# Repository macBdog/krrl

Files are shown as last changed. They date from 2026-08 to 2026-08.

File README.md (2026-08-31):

# KRRL-01

Control software and operator UI for the KRRL-01 vinyl record lathe.

**Hardware:** Raspberry Pi 4 (brain + audio + camera) and Arduino Mega 2560 (real-time motors and IO).  
**OS:** Raspberry Pi OS Lite 64-bit (Debian). See [docs/OS.md](docs/OS.md).

The Pi never generates step pulses. The Mega owns platter, X (lead screw), Z (depth), heated stylus PID, chip vacuum, limits, and E-stop.

## Quick start (desktop, no hardware)

```bash
cd krrl-01
PYTHONPATH=host python3 -m krrl --dry-run --port 8080
```

Open http://127.0.0.1:8080 — Live, Experiment, Cut, and Setup all run against a Mega simulator.

```bash
PYTHONPATH=host python3 -m krrl.check
```

## Pi (with Mega)

1. Flash **Raspberry Pi OS Lite 64-bit**.
2. Run `sudo bash deploy/tune-pi.sh`.
3. Copy this tree to `/opt/krrl-01`.
4. `sudo cp deploy/krrl.service /etc/systemd/system && sudo systemctl enable --now krrl`
5. Connect the Mega on USB (`/dev/ttyACM0`). I2S DAC HAT for the cutter amp; not the 3.5 mm jack.

## Layout

| Path | Role |
|---|---|
| `firmware/krrl_mega/` | Mega 2560 sketch (lathe) |
| `firmware/krrl_player/` | Nano sketch (player turntable variant) |
| `host/krrl/` | Python host |
| `ui/` | Operator console |
| `config/machine.yaml` | Calibration and devices |
| `docs/PROTOCOL.md` | Serial line protocol |
| `docs/PLAYER.md` | Player turntable variant |
| `docs/TACHOMETER.md` | Optional optical index monitor + marking/machining |
| `docs/CALIBRATION.md` | Open-loop platter speed calibration |
| `hardware/` | Drive/bearing/belt/stepper/phono notes + BOM |
| `deploy/` | systemd, PipeWire, OS tune |

## Player variant

A lower-cost, playback-only turntable on an **Arduino Nano only** (no Pi, no UI):
33/45/78 with ±8% pitch and start/stop, reusing the lathe belt drive, TMC2209
driver and motion core. See [docs/PLAYER.md](docs/PLAYER.md).

## Cut v1

Constant pitch only. Groove feed is `mm/s = rpm/60 * (25.4 / lpi)`. Variable-pitch preview is reserved for v2.

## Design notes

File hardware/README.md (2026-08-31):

# KRRL-01 hardware notes

Engineering notes and bill of materials for the mechanical drive and the player's
phono electronics. These are design notes, not a build manual — dimensions are
targets to design around, and part numbers are representative families, not
mandated SKUs.

## Shared drive architecture

The lathe and the standalone player share one drive: a **raised platter on a
central spindle, belt-driven around the spindle**, with the belt **tensioner
around that central shaft**. Raising the platter leaves the space underneath for
the lathe's **X-axis lead screw and carriage**, which passes below the platter.
The player uses the identical drive minus the X/Z/cutter hardware.

```
                 14" (356 mm) platter
   ┌──────────────────────────────────────────────┐
   └───────────────────────┬────────────────────────┘
              sub-platter / belt pulley (on spindle)
        ╔═══════════════════╪═══════════════════╗
        ║  bearing cartridge (moment-stiff)     ║  <- rigidity lives here
        ╚═══════════════════╪═══════════════════╝
                          spindle
   ── belt ── ( motor pulley )      ( idler tensioner )
   ─────────────── X-axis lead screw runs UNDER platter ───────────────
                          plinth / chassis
```

Design consequences that thread through the rest of these notes:

- **Rigidity is a moment problem.** The cutting stylus and the record rim sit at
  ~178 mm radius, so what matters is the platter's resistance to *tilting*, set
  almost entirely by the spindle bearing arrangement (see `drive.md`).
- **The belt sets the layout, not a big reduction.** The step ISR runs at
  `ISR_HZ = 20 kHz` and a step needs two ticks, so the platter step rate must
  stay below ~10 kHz (keep < 8 kHz for margin). At the base `steps_per_rev` of
  3200 and 78 rpm that is 4160 steps/s, so the belt ratio must stay near **1:1
  (≤ ~2:1)**. The belt is there for the raised-platter geometry and vibration
  isolation, not gearing.
- **Speed is open-loop.** There is no runtime speed feedback; absolute accuracy
  comes from calibrating `steps_per_rev` (see
  [`docs/CALIBRATION.md`](../docs/CALIBRATION.md)). The player has no speed
  sensor; the lathe may optionally fit a once-per-rev optical index as a passive
  at-speed monitor ([`docs/TACHOMETER.md`](../docs/TACHOMETER.md)).

## Contents

| File | Covers |
|---|---|
| [`drive.md`](drive.md) | Platter bearings, belt spec, stepper + driver, belt tensioner |
| [`phono.md`](phono.md) | Minimal-component phono amplification + RIAA EQ (player) |
| [`BOM.csv`](BOM.csv) | Consolidated bill of materials (lathe / player / both) |
| [`player_pcb/`](player_pcb) | Player single-board KiCad design (Nano + TMC2209 + RIAA + I/O), fab outputs |

## Related

- Firmware: [`firmware/krrl_mega/`](../firmware/krrl_mega) (lathe),
  [`firmware/krrl_player/`](../firmware/krrl_player) (player).
- Speed calibration: [`docs/CALIBRATION.md`](../docs/CALIBRATION.md).
- Optical index marking/machining: [`docs/TACHOMETER.md`](../docs/TACHOMETER.md).

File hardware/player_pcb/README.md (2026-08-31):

# Player mainboard (KiCad)

A single fabricable 2-layer PCB that carries the whole player turntable
electronics: the **Arduino Nano**, a **TMC2209** stepper-driver module, the
**RIAA phono preamp**, and all **front-panel I/O**. Speed is open-loop
feedforward (see [`docs/CALIBRATION.md`](../../docs/CALIBRATION.md)); the board
has no speed sensor.

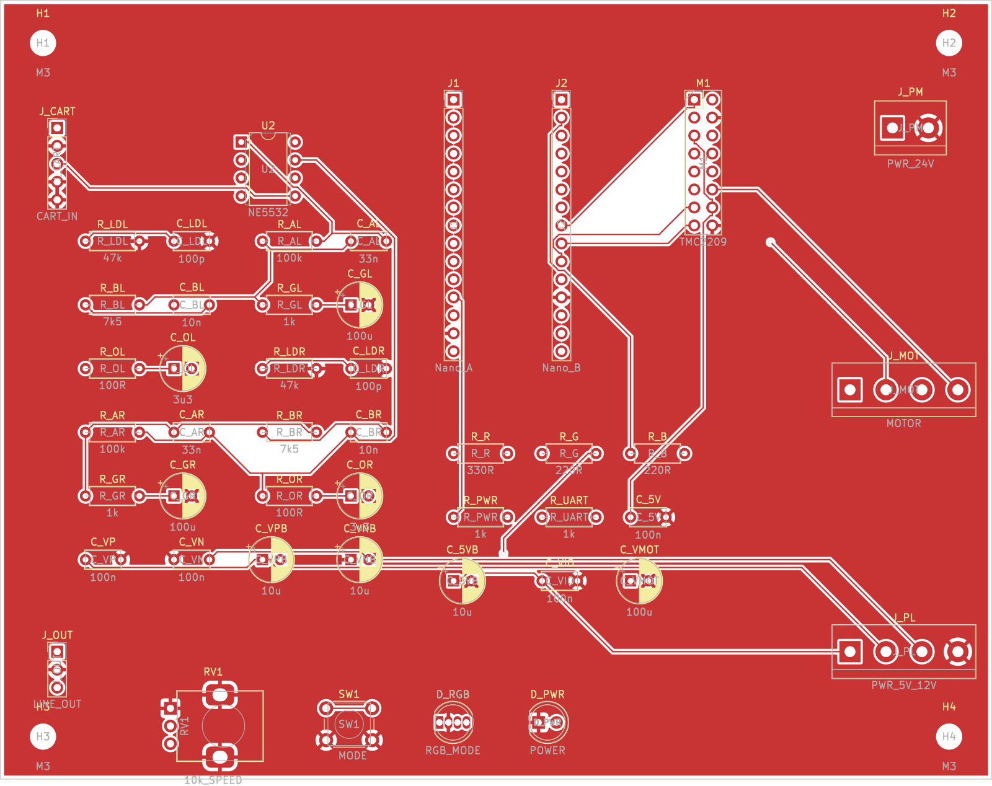
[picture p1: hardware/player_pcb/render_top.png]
Player mainboard — top


Open in KiCad 7+: `krrl_player.kicad_pro` (board `krrl_player.kicad_pcb`). It is a
**standalone board** (no schematic sheet) — every connection is defined by the
board nets, tabulated below and in [`NETLIST.txt`](NETLIST.txt).

## Board sections

- **Left:** analog phono — cartridge input `J_CART`, `NE5532` (`U2`), the RIAA
  network, and line output `J_OUT`.
- **Centre/right:** digital — the Nano (`J1`/`J2`) and the TMC2209 module (`M1`).
- **Right edge:** power/motor terminals (`J_PM`, `J_PL`, `J_MOT`).
- **Front edge:** controls — mode button `SW1`, speed pot `RV1`, RGB mode LED
  `D_RGB`, power LED `D_PWR`.

The analog section sits at the opposite end from the motor terminal and TMC to
keep the 5 mV cartridge signal away from stepper switching (see
[`hardware/phono.md`](../phono.md) for the EMI/grounding rationale).

## Power supply (external, separate — specify when ordering the PSU)

The board has **no on-board regulators**; it expects an external multi-rail
supply. A linear analog rail keeps the phono stage quiet.

| Rail | Use | Min current | Enters at |
|---|-----|---|---|
| +24 V | Stepper (TMC `VMOT`) | ~1.5 A | `J_PM` pin 1 |
| +5 V | Logic (Nano, TMC `VIO`, LEDs) | ~0.5 A | `J_PL` pin 1 |
| +12 V | Phono op-amp V+ | ~50 mA | `J_PL` pin 2 |
| −12 V | Phono op-amp V− | ~50 mA | `J_PL` pin 3 |
| GND | Common return | — | `J_PM` pin 2, `J_PL` pin 4 |

All grounds meet at the board (single GND pour = star point). Keep the PSU's
motor return and analog return joined only at the supply to avoid a ground loop.
±12 V may be ±15 V if preferred (NE5532 max ±22 V).

## Connectors

**`J_PM` — 24 V motor power** (2-pos): 1 = +24 V, 2 = GND.
**`J_PL` — logic/analog power** (4-pos): 1 = +5 V, 2 = +12 V, 3 = −12 V, 4 = GND.
**`J_MOT` — stepper motor** (4-pos): 1 = 2B, 2 = 2A, 3 = 1A, 4 = 1B (coil pairs
1A/1B and 2A/2B).
**`J_CART` — cartridge in** (1×5): 1 = L-hot, 2 = L-gnd, 3 = R-hot, 4 = R-gnd,
5 = shield (2/4/5 → GND).
**`J_OUT` — line out** (1×3): 1 = L, 2 = GND, 3 = R (fit an RCA pigtail).

## Front panel

| Control | Part | Wiring |
|---|---|---|
| Mode button | `SW1` momentary | to `MODE` (Nano D6, `INPUT_PULLUP`) and GND |
| Speed pot | `RV1` 10k lin | 1 → GND, 2 (wiper) → A0, 3 → +5 V |
| Mode LED | `D_RGB` common-cathode | R/G/B anodes via `R_R`/`R_G`/`R_B` → D9/D10/D11; cathode → GND |
| Power LED | `D_PWR` | +5 V → `R_PWR` → anode; cathode → GND |

RGB colours (firmware): off = stopped, green = 33, blue = 45, red = 78; blinks
while spinning up, solid at speed.

## Nano pin usage (`J1` side A, `J2` side B)

| Net | Nano pin | Header |
|-----|---|---|
| +5 V | 5V | J1.12 |
| GND | GND | J1.14, J2.12 |
| Speed pot wiper | A0 | J1.4 |
| STEP | D3 | J2.10 |
| DIR | D4 | J2.9 |
| EN | D5 | J2.8 |
| MODE | D6 | J2.7 |
| LED R / G / B | D9 / D10 / D11 | J2.4 / J2.3 / J2.2 |
| TMC UART (opt.) | D1 TX / D0 RX | J2.15 / J2.14 |

## TMC2209 module header (`M1`, 2×8)

Follows the StepStick / A4988-compatible layout so a SilentStepStick-class
TMC2209 mounts here. **Verify your module's pinout — especially the PDN/UART
pin — before soldering.**

| Pin | Net | Pin | Net |
|----:|-----|----:|-----|
| 1 | EN | 2 | +24 V (VMOT) |
| 3 | MS1 → +5 V | 4 | GND |
| 5 | MS2 → +5 V | 6 | 2B |
| 7 | PDN/UART | 8 | 2A |
| 9 | (nc) | 10 | 1A |
| 11 | (nc) | 12 | 1B |
| 13 | STEP | 14 | +5 V (VIO) |
| 15 | DIR | 16 | GND |

`MS1`/`MS2` are tied to +5 V for **1/16 microstepping** in standalone STEP/DIR
mode (matches the firmware `steps_per_rev = 3200`). For the optional UART build
(`-DTMC_UART`), the Nano UART reaches `PDN` via `R_UART` (1 k); set the module
address as needed.

## RIAA phono

One `NE5532` (`U2`) as two non-inverting active-feedback RIAA stages. Per-channel
values and the design rationale are in [`hardware/phono.md`](../phono.md):
47 k∥100 pF load, `R_A` 100 k / `C_A` 33 n / `R_B` 7.5 k / `C_B` 10 n feedback,
`R_G` 1 k + `C_G` 100 µF gain-set, `R_O` 100 Ω + `C_O` 3.3 µF output. Treat the
values as a verified-by-calculator starting point.

## Board specs / fabrication

- **2-layer** FR4, 1.6 mm, 1 oz copper; **140 × 110 mm**.
- Design rules: 0.2 mm track / 0.2 mm clearance; vias 0.8 mm / 0.4 mm; GND pours
  on both layers.
- Fab outputs: [`gerbers/`](gerbers) (RS-274X + Excellon `.drl`) and
  [`krrl_player_gerbers.zip`](krrl_player_gerbers.zip). BOM in
  [`BOM.csv`](BOM.csv).

### Regenerate

The board is generated from source (KiCad 7 `pcbnew` + freerouting):

```
FREEROUTING_JAR=/path/to/freerouting-1.9.0.jar ./route.sh   # place + net + autoroute
./fab.sh                                                    # gerbers + drill + renders
```

`build_pcb.py` is the source of truth for components and connections; edit it and
re-run to change the design.

## Status / caveats

- **Fully routed, 0 unrouted connections** at the rules above; placement and
  routing are auto-generated (freerouting) — review in KiCad before ordering.
- Verify the **TMC2209 module** and **RGB LED** pinouts against your exact parts.
- RIAA values and the external PSU rails should be confirmed for your build.
- This is a design deliverable validated by connectivity + Gerber export; it has
  **not been fabricated or bench-tested**.

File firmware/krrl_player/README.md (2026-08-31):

# Nano player firmware

Minimal belt-drive **playback** turntable: 33/45/78 with a ±8% pitch trim and a
single mode button, and nothing else. No host, no serial protocol, no cutter,
heater or vacuum. It reuses the KRRL-01 belt drive motor, TMC2209 driver and the
lathe's open-loop step-rate motion core (`playspeed.h`, `platter.cpp` derived
from `firmware/krrl_mega/motion.cpp`).

The front panel is a single **momentary mode button**, a **speed pot**, a
**multicolour (RGB) mode LED** and a **power LED** — matching the single-board
design in [`hardware/player_pcb/`](../../hardware/player_pcb).

Open `krrl_player.ino` in Arduino IDE (board: **Arduino Nano**, ATmega328P).
The default build is STEP/DIR only and needs no libraries.

## Wiring (Arduino Nano)

| Signal | Pin | Notes |
|---|-----|---|
| Platter STEP | D3 | to TMC2209 STEP |
| Platter DIR | D4 | to TMC2209 DIR |
| Platter EN | D5 | active LOW |
| MODE button | D6 | momentary to GND; cycles STOP → 33 → 45 → 78 |
| Mode LED R / G / B | D9 / D10 / D11 | common-cathode RGB, each anode via a series R |
| Speed pot | A0 | 10k linear pot wiper; ends to 5V and GND |
| TMC UART | D0/D1 | optional, `-DTMC_UART` (RX/TX to PDN_UART via 1k) |

The mode button is `INPUT_PULLUP`, wired button-to-ground. The speed pot is a
10k linear potentiometer: outer legs to 5V and GND, wiper to A0. Pins are in
`config.h`. The **power LED is hardwired to +5V** on the board (not a Nano pin).

**Mode button** cycles `STOP → 33 → 45 → 78 → STOP`; STOP spins the platter
down. The **RGB LED** shows the mode — off = stopped, green = 33, blue = 45,
red = 78 — blinking while spinning up and solid once at speed.

The **speed pot** is a continuous pitch trim: **centre detent reads 0%** (a small
deadband holds nominal speed), each end reaches **±8%**, smoothed so the platter
speed doesn't jitter.

## Speed: open-loop feedforward

Platter speed is open-loop — the step rate sets the speed, with no runtime
control loop and no on-board speed sensor. Set absolute speed by **calibration**
([`docs/CALIBRATION.md`](../../docs/CALIBRATION.md)); the fine trim is
`KRRL_SPEED_TRIM_PPM` in `playspeed.h` (or adjust `KRRL_PLATTER_STEPS_PER_REV`).
Speed verification is done with external calibration equipment, not by the
firmware. The `LED` at-speed indication reflects the feedforward ramp reaching
the commanded rate.

## TMC2209 current / microsteps (optional)

Default is STEP/DIR only; the driver runs at its jumper defaults. To set current
and microsteps over UART at boot:

1. Install [TMCStepper](https://github.com/teemuatlut/TMCStepper).
2. Build with `-DTMC_UART`.
3. Wire PDN/UART to the Nano hardware UART (D0/D1); driver address `00`
   (MS1/MS2 low), same as the lathe platter.

## Speed math

`playspeed.h` is shared, pure C, and unit-tested on the host:

```
cd firmware/krrl_player/test
c++ -std=c++11 -o test_playspeed test_playspeed.cpp && ./test_playspeed
```

Step rate is `sps = rpm / 60 * 3200`, matching the lathe platter
(`PLATTER_STEPS_PER_REV`). Pitch is multiplicative: `rpm * (1 ± pct/100)`.

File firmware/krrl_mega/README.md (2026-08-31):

# Mega 2560 firmware

Open `krrl_mega.ino` in Arduino IDE (board: **Arduino Mega or Mega 2560**).

Default build is STEP/DIR only and does not need libraries.

To configure TMC2209 current/microsteps over UART at boot:

1. Install [TMCStepper](https://github.com/teemuatlut/TMCStepper)
2. Add compile flag `-DTMC_UART` (Arduino CLI) or `#define TMC_UART` in `config.h`
3. Wire PDN/UART to Serial1 (pins 18/19) with the usual 1 kΩ TX/RX arrangement
4. Set MS1/MS2 addresses: platter 00, X 01, Z 10

Pins match `config.h` and the comments in `config/machine.yaml`.

## Platter speed: open-loop feedforward

The platter runs open-loop — the step rate sets the speed, with no runtime
control loop. Set absolute speed by **calibration**
([`docs/CALIBRATION.md`](../../docs/CALIBRATION.md)); the fine trim is
`PLATTER_CAL_PPM` in `config.h` (or adjust `PLATTER_STEPS_PER_REV`).

The 1-pulse-per-rev optical tach (`PIN_TACH`, pin 3) is a **passive monitor**:
it feeds telemetry `rpm` and the `START` at-speed interlock but does not steer
the step rate. See [`docs/TACHOMETER.md`](../../docs/TACHOMETER.md) for the
sensor and the platter marking/machining (shared with the player variant).

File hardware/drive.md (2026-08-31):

# Drive: bearings, belt, stepper, tensioner

Shared by the lathe and the player. See [`README.md`](README.md) for the
raised-platter, belt-around-the-spindle architecture and the constraints it
imposes.

## 1. Platter spindle bearings (rigidity at the 14" rim)

The platter is 356 mm (14") diameter, so the load that matters is the **tilting
moment** at the ~178 mm rim — from the cutting stylus on the lathe and from any
off-centre load on either machine. A bearing that is stiff radially but weak in
*moment* lets the rim nod by microns, which reads as runout, wow and (on the
lathe) a wandering cut. Maximise **moment (tilt) stiffness**, then radial, then
axial; keep friction and noise low for the audio path.

Target: platter face and rim runout **< 5 µm TIR**; no perceptible rock at the
rim by hand.

### Recommended: preloaded angular-contact pair, back-to-back (baseline)

Two precision angular-contact ball bearings (7205/7206-class, **bore 25–30 mm**,
**P5/ABEC-5 or better**) mounted **back-to-back (DB / "O")** in a rigid cartridge.
Back-to-back places the contact lines' apexes *outboard*, which widens the
effective support span and is what buys the tilt stiffness at the rim. Set a
**light-to-medium axial preload** (ground spacer or a preload nut + Belleville
washer) to remove all play — preload is what makes it feel solid.

- Spindle: hardened, ground steel, **Ø25–30 mm**, seats to h6; housing bores H7.
- Space the two bearings as far apart on the spindle as the raised height allows;
  span dominates tilt stiffness.
- Angular-contact (point/line contact, low drag) runs quieter than tapered
  roller — preferred for the player.

### Alternative: thin-section crossed-roller bearing (most compact/stiff)

A single **crossed-roller** (e.g. THK RA/RB, IKO CRB, Kaydon) or four-point-contact
thin-section bearing takes radial, axial **and moment** load in one race. Highest
tilt stiffness per height and ideal for a raised platter with a large central
boss, at higher cost and more sensitivity to housing flatness. Size the bore to
the sub-platter boss (typically Ø50–90 mm).

### Alternative: preloaded tapered-roller pair (max stiffness, more rumble)

Back-to-back tapered rollers (machine-tool spindle style) give the highest
stiffness and load capacity — attractive for heavy cutting — but have more drag
and running noise, so they are a poorer fit for the player. Use only if lathe
cutting loads demand it.

### Avoid

A single deep-groove ball bearing + a flat thrust washer is cheap but has almost
no moment stiffness — the 14" rim will nod. Not acceptable for this goal.

## 2. Drive belt

The belt exists for **layout and vibration isolation**, not reduction (ratio must
stay near 1:1 — see the step-rate ceiling in `README.md`).

- **Type:** endless **flat ground belt** (polyurethane/neoprene, ~**6 mm wide ×
  0.5–0.65 mm**) or a **round belt Ø3–4 mm**. Both mechanically low-pass motor
  vibration, keeping rumble/flutter down — the classic turntable choice.
  A **GT2/6 mm timing belt** is the positive-drive alternative (exact ratio, no
  creep) but couples motor cogging into the platter; only choose it if belt creep
  under lathe cutting load is a problem, and rely on TMC stealthChop to keep the
  motor smooth.
- **Pulleys:** **crowned** (slightly barrelled) so a flat/round belt self-tracks
  — no flanges, cleaner look. The sub-platter/spindle is the driven pulley; the
  motor pulley diameter is chosen to keep ratio ≈ 1:1.
- **Wrap:** aim for **≥ 180°** contact on the drive pulley; the idler tensioner
  (below) is what increases wrap and holds it constant.
- **Tension:** low and constant — of order **2–5 N** for a round/flat isolation
  belt. Enough to avoid slip under acceleration/cut load, no more (over-tension
  loads the spindle bearing and adds rumble).

## 3. Stepper and driver

- **Motor:** **NEMA 17, high-torque** as the shared baseline — 42 mm frame,
  **≥ 0.5 N·m holding**, ~**1.5 A/phase**, 200 full-steps/rev (1.8°), e.g. a
  48 mm-stack `17HS19-2004S1`-class. Ample for the player and light cuts; the
  platter's large inertia is handled by the firmware's rate slew, and open-loop
  torque margin resists cut load without losing steps.
- **Heavy cutting option:** **NEMA 23** (57 mm, 1.2–1.9 N·m) if lathe cutting
  loads are high. Note a torquey NEMA 23 can exceed the TMC2209's practical
  ~1.7 A RMS — pair it with a **TMC5160** or an external step/dir driver
  (DM542-class) instead.
- **Driver:** **TMC2209** (already in firmware — STEP/DIR at runtime, UART config
  at boot; `firmware/*/tmc.cpp`). Run **stealthChop** for a silent platter on the
  player; **spreadCycle** is available when the lathe needs peak torque. Set RMS
  current to the motor (firmware default 800 mA for the platter). **16
  microsteps** balances smoothness against the step-rate ceiling.
- **Supply:** **24 V** to the driver (better torque headroom, still within the
  TMC2209's ~28 V limit); logic at 5 V. Keep the motor supply electrically clean
  and separated from the phono stage (see `phono.md`).

## 4. Belt tensioner (aesthetic, constant-tension)

A **constant-tension** device beats a fixed one: it takes up belt stretch and
thermal drift and keeps flutter low. Two clean options, both hiding the mechanism
under the raised platter:

### Preferred: pivoting idler arm with concealed preload

A short **polished/anodised aluminium arm** pivots on a bearing post and carries a
small **ball-bearing crowned idler pulley** that rides the slack side of the belt.
Preload the arm with either:

- a **concealed extension spring** tucked inside the arm or behind the pillar, or
- a **magnetic** preload — a pair of small neodymium magnets (one on the arm, one
  on the chassis) tuned to the target belt force — giving a spring-free, wear-free,
  visually clean pull.

The arm both **tensions** and **increases wrap** on the drive pulley. Set the
preload to land the 2–5 N belt tension; a soft rate keeps tension near-constant
over the arm's travel.

### Minimalist: eccentric motor pod

Mount the motor on a **round pod with an eccentric bore** (or on a slotted plate);
rotate/slide to tension, then lock with a single hidden screw. No visible
spring — the tension "mechanism" reads as a clean turned boss. Fixed rather than
constant-tension, so revisit after break-in.

Either way use a **bearing idler** (not a bushing) so it adds no drag or noise,
and crown it so the belt self-centres.

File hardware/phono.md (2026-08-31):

# Phono amplification and RIAA EQ (player)

The standalone player needs to turn a cartridge's tiny signal into a line-level
output with the **RIAA** replay curve applied. This note targets a **moving-magnet
(MM)** cartridge and the **fewest components** that do it well.

> The hard part here is not the circuit — it is **noise**. An MM output is only
> ~5 mV, sitting centimetres from a stepper and its driver. Read the EMI section
> before the topology; it decides whether this works.

## Cartridge and loading

- **Cartridge:** moving-magnet (MM). Output ~**3–5 mV @ 1 kHz, 5 cm/s**.
- **Load:** **47 kΩ** to ground in parallel with **~100–220 pF** (include tonearm
  cable capacitance in the total; many MM carts want ~200–300 pF total). Put the
  47 kΩ and a small load cap right at the preamp input.

## Target response

Apply the inverse-RIAA replay curve, i.e. three time constants:

| Constant | Freq | Role |
|---|---|---|
| 3180 µs | 50.0 Hz | bass turnover (boost below) |
| 318 µs | 500 Hz | mid |
| 75 µs | 2122 Hz | treble roll-off |

Aim for the curve within **±0.5 dB** (1% metal-film resistors, 1–2.5% film caps).
Midband gain ~**40 dB (×100) @ 1 kHz** brings 5 mV up to ~0.5 V line level.

## Minimal topology: one dual op-amp, active-feedback RIAA

Fewest parts: a single **dual op-amp** does both channels, each in a
**non-inverting, active-feedback RIAA** stage. Per channel that is one gain
device plus a handful of passives — no separate buffers or multi-stage EQ.

- **Op-amp:** low-noise, unity-gain-stable **NE5532** (cheap, quiet), or
  **OPA2134 / LM4562** for lower noise/distortion. One dual package = stereo.
- **Per channel (see values below):** 47 kΩ load + load cap; gain resistor `Rg`
  (with a large DC-blocking cap to ground); feedback network `R_A, C_A` and
  `R_B, C_B` that set the three time constants; input DC-block + a small RF cap.

```
  cart o──┬──[47k]──┬── + in >\
          │        (Cload)     \____ out ──[Rout]──|| Cout ── line out
        (Cin DC)               /
                   ┌── − in ─/
                   │
          Rg ─ Cg(DC) ─ gnd        feedback: out ─ R_A ─┬─ − in
                                                        └─(R_B + C_B)┘,  C_A across R_A
```

### Starting values (verify with a RIAA calculator, then trim)

These land the three breakpoints close; C_A/R_B interact, so verify and trim on
the bench or in a calculator before committing:

- `Cload` ≈ 100 pF (bring total incl. cable to what the cartridge specifies)
- `Rg` ≈ 1 kΩ, `Cg` ≈ 100 µF (sets midband gain, blocks DC)
- `R_A` ≈ 100 kΩ, `C_A` ≈ 33 nF  (anchors the 3180 µs turnover)
- `R_B` ≈ 7.5 kΩ, `C_B` ≈ 10 nF  (`R_B·C_B` = 75 µs, the treble roll-off — exact)
- `Cin` ≈ 1–3.3 µF film (input DC block), plus ~100–470 pF at the input node for RF
- `Rout` ≈ 100 Ω, `Cout` ≈ 2.2–10 µF (output DC block)

### Easier-to-tune alternative

If you have a bench and want the curve nailed without interaction: a **flat
low-noise gain stage → passive RIAA network → buffer**. More parts, but each time
constant is an independent RC, so it is simpler to trim. Choose this only if the
single-stage feedback curve is fighting you.

A **dedicated phono IC** is the even-fewer-parts route if you prefer an
integrated part over the op-amp + passives, at the cost of flexibility.

## Power

- **± 12–15 V dual rail** from a small **linear** regulated supply is simplest and
  quietest. If running single-supply (e.g. 24 V), bias the op-amp to a
  **virtual ground** (rail/2) and AC-couple in and out.
- **Do not share the motor's 24 V rail.** Give the phono stage its own regulated,
  filtered supply; the stepper's switching current on a shared rail will inject
  hum/buzz straight into a 5 mV signal.
- Decouple each op-amp rail with 100 nF + 10 µF at the package.

## EMI, grounding and layout (the part that actually matters)

- **Separate the phono board from the motor and driver** physically and put it in
  a **shielded (steel/mu-metal) enclosure**. Keep step/dir and motor-phase wires
  well away from the cartridge leads; twist the motor pairs.
- **Shielded cartridge leads**, as short as practical; connect the shield at one
  end only (preamp end) to avoid a ground loop.
- **Star ground:** one reference point; separate the motor-supply return from the
  audio ground and join only at the star. No ground loops between the platter
  frame, motor supply, and audio.
- Run the platter motor in **stealthChop** (TMC2209) for the quietest electrical
  and acoustic signature during playback.
- Add the small input RF cap and keep the input node tiny; the 47 kΩ node is a
  perfect antenna otherwise.

## Output

Line level ~**0.3–1 V RMS** at an output impedance of ~100 Ω, AC-coupled. Feed a
line input / integrated amp, not a second phono input.

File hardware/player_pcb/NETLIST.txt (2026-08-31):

KRRL-01 Player board — netlist (net: pads)

+12V: C_VP.1, C_VPB.1, J_PL.2, U2.8
+24V: C_VMOT.1, J_PM.1, M1.2
+5V: C_5V.1, C_5VB.1, C_VIO.1, J1.12, J_PL.1, M1.14, M1.3, M1.5, RV1.3, R_PWR.1
-12V: C_VN.2, C_VNB.2, J_PL.3, U2.4
BML: C_BL.2, R_BL.1
BMR: C_BR.2, R_BR.1
DIR: J2.9, M1.15
EN: J2.8, M1.1
FBL: C_AL.1, R_AL.1, R_BL.2, R_GL.1, U2.2
FBR: C_AR.1, R_AR.1, R_BR.2, R_GR.1, U2.6
GML: C_GL.1, R_GL.2
GMR: C_GR.1, R_GR.2
GND: C_5V.2, C_5VB.2, C_GL.2, C_GR.2, C_LDL.2, C_LDR.2, C_VIO.2, C_VMOT.2, C_VN.1, C_VNB.1, C_VP.2, C_VPB.2, D_PWR.1, D_RGB.2, J1.14, J2.12, J_CART.2, J_CART.4, J_CART.5, J_OUT.2, J_PL.4, J_PM.2, M1.16, M1.4, RV1.1, RV1.MP, R_LDL.2, R_LDR.2, SW1.2
INL: C_LDL.1, J_CART.1, R_LDL.1, U2.3
INR: C_LDR.1, J_CART.3, R_LDR.1, U2.5
LEDB: J2.2, R_B.1
LEDG: J2.3, R_G.1
LEDR: J2.4, R_R.1
LOUTL: C_OL.2, J_OUT.1
LOUTR: C_OR.2, J_OUT.3
M1A: J_MOT.3, M1.10
M1B: J_MOT.4, M1.12
M2A: J_MOT.2, M1.8
M2B: J_MOT.1, M1.6
MODE: J2.7, SW1.1
OLL: C_OL.1, R_OL.2
OLR: C_OR.1, R_OR.2
OUTL: C_AL.2, C_BL.1, R_AL.2, R_OL.1, U2.1
OUTR: C_AR.2, C_BR.1, R_AR.2, R_OR.1, U2.7
PDN: J2.14, M1.7, R_UART.2
POTW: J1.4, RV1.2
PWRA: D_PWR.2, R_PWR.2
RGB_B: D_RGB.4, R_B.2
RGB_G: D_RGB.3, R_G.2
RGB_R: D_RGB.1, R_R.2
STEP: J2.10, M1.13
TX: J2.15, R_UART.1

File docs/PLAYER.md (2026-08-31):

# KRRL-01 Player (Nano variant)

A separate, lower-cost **playback** turntable. Where the lathe pairs a
Raspberry Pi with an Arduino Mega, the player is an **Arduino Nano only** — pure
hardware, no host, no UI, no serial protocol.

## What it does

- Playback at **33⅓ / 45 / 78** rpm, selected by a single **mode button**
  (cycles STOP → 33 → 45 → 78) with a **multicolour LED** showing the mode.
- Continuous **speed pot** (pitch trim) of **±8%** (centre detent = 0%).
- Smooth rate-slewed belt spin-up/down.
- **Open-loop feedforward speed** — no runtime control loop and **no speed
  sensor**. Set absolute speed via [docs/CALIBRATION.md](CALIBRATION.md). The
  LED reflects the feedforward ramp reaching the commanded rate.

No cutter, heater, vacuum, camera, audio pipeline, homing or limits — none of the
lathe's cut path is present.

## What it shares with the lathe

- The **belt drive stepper motor** and pulley/belt ratio.
- The **TMC2209** driver (STEP/DIR at runtime, optional UART config at boot).
- The **motion core**: the same Timer1 phase-accumulator step generation and the
  same open-loop speed math (`sps = rpm / 60 * 3200`). The platter steps-per-rev
  matches the lathe (`firmware/krrl_mega/config.h`, `config/machine.yaml`) and
  the shared math lives in `firmware/krrl_player/playspeed.h`.
- The **open-loop platter drive** and the calibration approach. See
  [docs/CALIBRATION.md](CALIBRATION.md). (The optional optical index monitor is a
  lathe-only feature — [docs/TACHOMETER.md](TACHOMETER.md).)

## Controls

A single momentary **mode button**, a **speed pot**, a **multicolour (RGB) mode
LED** and a **power LED**. Wiring and pins are in
[`firmware/krrl_player/README.md`](../firmware/krrl_player/README.md); the
single-board design is in [`hardware/player_pcb/`](../hardware/player_pcb).

| Control | Action |
|---|---|
| Mode button | Cycle STOP → 33 → 45 → 78 (STOP spins down) |
| Speed pot | Continuous ±8% pitch trim of the running speed; centre = 0% |
| RGB mode LED | off = stopped, green = 33, blue = 45, red = 78; blinks while spinning up |
| Power LED | Hardwired to +5V; power present |

## Firmware

`firmware/krrl_player/` — build for **Arduino Nano** (ATmega328P). Default build
is STEP/DIR only and needs no libraries. See the firmware README for the TMC2209
UART option and the host-side test of the speed math.

## Board

A single fabricable KiCad PCB (Nano + TMC2209 + RIAA phono + I/O) is in
[`hardware/player_pcb/`](../hardware/player_pcb), which also specifies the
required external power supply.

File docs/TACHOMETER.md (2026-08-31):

# Optical index mark (passive at-speed monitor)

Both KRRL-01 machines — the lathe (Mega) and the player (Nano) — drive the same
belt-driven platter with a stepper, **open-loop**. A stepper is nearly
synchronous, so the commanded step rate *is* the speed; torque margin keeps it
there. There is **no runtime speed control loop** — absolute accuracy comes from
[calibration](CALIBRATION.md), not feedback.

On the **lathe**, an optional **once-per-revolution optical index mark** is still
useful as a **passive at-speed / lost-step monitor**: it reports the platter's
actual speed for telemetry and the `START` interlock, but it never steers the
step rate. (A single mark per rev is far too slow to close a speed loop, and it
only sees average speed, not wow/flutter — which is why the drive is open-loop.)

The **player** carries **no speed sensor**: it is fully open-loop and its
at-speed LED simply reflects the feedforward ramp reaching the commanded rate.

The platter **marking and machining** below therefore apply to the lathe (or any
build where you choose to fit the sensor); both firmwares run without it.

## How it works (lathe)

1. **One index mark per revolution** on the platter passes an optical sensor
   mounted on the chassis. The sensor outputs one clean pulse per rev.
2. The pulse edge fires the `motion_tach_isr` interrupt, which timestamps the
   edge with `micros()` and records the **mark-to-mark period**. Edges closer
   than 2 ms (noise) or slower than 2 s are rejected.
3. Measured speed is `rpm = 60 000 000 / (period_us × marks_per_rev)`. With one
   mark per rev (`marks_per_rev = 1`) the period in microseconds is the whole
   revolution; `motion.cpp` computes this inline.
4. The measured value drives **indication only**: telemetry reports `rpm`, and
   the `START` interlock requires the platter to be at speed before a cut. The
   commanded step rate stays pure feedforward regardless.

**No sensor fitted:** no pulse ever arrives, so the lathe treats the feedforward
speed as at-speed. Fitting the sensor later needs no firmware change.

Marks per rev is fixed at **1** (`tach_ppr` in
[`config/machine.yaml`](../config/machine.yaml)). Use exactly one index feature.

For **absolute speed accuracy**, do not rely on this once-per-rev signal — see
[docs/CALIBRATION.md](CALIBRATION.md) for the sensor rigs and procedure.

## Sensor and wiring

Use a 5 V digital optical sensor with a clean (ideally Schmitt-triggered) output:

- **Through-beam / slotted photo-interrupter** (e.g. a slot-type opto): the
  platter index feature (a slot or hole in a depending rim) passes through the
  slot. Most robust — immune to surface finish and ambient light. **Preferred.**
- **Reflective sensor** (e.g. TCRT5000-class IR reflectance): reads a single
  high/low-contrast mark on a platter face. Simpler to mount; needs a good
  contrast mark and a fixed standoff.

| Signal | Lathe (Mega) |
|---|---|
| Tach input | pin `3` (`PIN_TACH`) |
| Sensor Vcc / GND | 5 V / GND |

(The player has no tach input; it does not read a speed sensor.)

The input uses `INPUT_PULLUP` and triggers on the **rising** edge. Keep the lead
short or shielded; add a 100 nF cap at the sensor if the output is noisy. Aim
for one crisp pulse per rev with fast edges — mount the sensor so the mark fully
clears it between revolutions.

## How to mark the platter

Pick the option that matches your sensor. Either way, the rule is **one index
feature per revolution**, at a fixed radius, cleared by the sensor each turn.

### Option A — index slot/hole in the rim (through-beam / slotted sensor)

Best for a platter with a **depending skirt** (a vertical cylindrical wall on the
underside). Drill **one** radial hole (or mill one slot) through the skirt so it
lines up with the slot sensor.

- One hole/slot only.
- Width ≥ 1.5× the sensor's effective beam so it triggers reliably; a
  3–4 mm hole suits most slot optos.
- Put it on a dedicated band clear of screws, spokes and other holes so nothing
  else breaks the beam.

### Option B — single index mark on a face (reflective sensor)

Best for a flat platter with no skirt. Create **one** high-contrast mark on the
underside at a set radius, on an otherwise uniform annular **tach track**:

- Bright bare-aluminium track with **one matte-black mark** (paint/anodise), or
  a matte/black track with **one reflective mark** (foil tape).
- Mark ~6–8 mm long (arc) × the track width; only one, at one radius.
- Hold the sensor standoff the sensor datasheet calls for (TCRT5000 ≈ 2–5 mm).

## Machining the tach feature on a manual lathe

You are turning the platter anyway; add the tach feature in the same setup so it
is concentric with the spindle. Below assumes an aluminium platter.

### Tooling

- Manual lathe with a 3- or 4-jaw chuck (or faceplate) able to hold the platter.
- Facing and turning tools to true the underside and, for Option B, to turn a
  clean annular **tach track**.
- A **parting/grooving tool** if you prefer a turned groove as the reflective
  track boundary.
- For Option A: a **slotting/index hole** — a centre/spotting drill plus a
  3–4 mm drill, run in the tailstock (for an axial hole) or, for a radial hole
  in a skirt, a drill in the tailstock with the platter clamped on its side in a
  fixture, or a milling attachment / drill press. A small end mill if you want a
  slot instead of a hole.
- Layout tools: height gauge or surface gauge + scriber, dividers, dial
  indicator to confirm runout, deburring tool/fine file, and a fine-tip paint
  pen or foil tape for Option B.
- Eye protection; deburr and clean all swarf (it is ferromagnetic-free but still
  fouls optics and bearings).

### Steps

1. **Mount and true.** Hold the platter and indicate it in so radial runout is a
   few hundredths of a millimetre. Face the underside flat.
2. **Turn the tach track (Option B) or verify the skirt (Option A).** For a
   reflective mark, turn a shallow, uniform annular band ~8–10 mm wide at a
   convenient radius (e.g. near the rim, clear of the bearing and drive belt).
   For a slotted sensor, confirm the skirt runs true and pick a radius/height
   where the slot opto can straddle it.
3. **Set the sensor radius.** Decide the radius the sensor will sit at and record
   it — the mark/hole must be at that radius. Keep it clear of the belt path,
   mounting bosses and balance features.
4. **Cut the single index feature.**
   - *Option A:* spot then drill **one** 3–4 mm hole through the skirt (or mill
     one slot). Do not add a second hole in the sensed band.
   - *Option B:* leave the machined band as the uniform background; the actual
     mark is applied after finishing (step 6).
5. **Deburr and check balance.** Remove burrs so edges are crisp (crisp edges =
   clean pulse). A single small hole adds negligible imbalance at 33–78 rpm; if
   you want to balance it, drill a **blind** hole of equal mass **180° opposite**
   on a *different, non-sensed* band so it never enters the beam.
6. **Apply the contrast mark (Option B only).** After final finishing, add
   exactly **one** matte-black mark (or one reflective foil mark on a dark track)
   ~6–8 mm long at the sensor radius. Keep the rest of the track uniform.
7. **Fit and verify (lathe).** Mount the sensor at the recorded radius and
   standoff. Spin the platter by hand and confirm the sensor toggles **once per
   revolution** with clean high/low levels. Then power up and confirm the lathe
   reports `rpm` and reaches `READY`/at-speed. Remember this only confirms the
   monitor works — set true speed via [calibration](CALIBRATION.md).

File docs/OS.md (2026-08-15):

# Raspberry Pi OS for KRRL-01

**Distro: Raspberry Pi OS Lite 64-bit** (Debian Bookworm or successor Trixie).

Not Ubuntu, DietPi, or a desktop image. Official Pi 4 I2S overlays, `libcamera`, USB serial, and a slow Debian package cadence matter more here than a longer Ubuntu LTS window.

## Why Lite

Motor pulses are on the Mega. The Pi still must play a WAV for the length of a side without resampling or scheduler gaps. A compositor, Bluetooth, and Wi-Fi power save work against that.

## Install outline

1. Raspberry Pi Imager → Raspberry Pi OS Lite (64-bit) → enable SSH, set user `krrl`.
2. Boot, `sudo apt update && sudo apt install -y python3 python3-serial mpv ffmpeg v4l-utils`
3. I2S DAC HAT (HiFiBerry DAC2 HD or equivalent): enable the vendor overlay in `/boot/firmware/config.txt`. Do not use the onboard 3.5 mm jack for the cutter amp.
4. `sudo bash /opt/krrl-01/deploy/tune-pi.sh`
5. `sudo cp /opt/krrl-01/deploy/krrl.service /etc/systemd/system/`
6. `sudo systemctl enable --now krrl`

## Audio

PipeWire on current Raspberry Pi OS. Pin 48 kHz, quantum 1024 (see `deploy/pipewire-krrl.conf`). Playback is `mpv --audio-device=…` so the mixer's hot path is native.

Optional later: official `PREEMPT_RT` kernel. Not required for v1.

## Camera

USB UVC (`/dev/video0`) or CSI via `libcamera`. The host serves MJPEG at `/api/camera`.

## Serial

Mega appears as `/dev/ttyACM0`. User `krrl` must be in group `dialout`.

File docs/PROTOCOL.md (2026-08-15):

# KRRL-01 serial protocol

USB CDC, **115200 8N1**, newline-terminated ASCII (`\n`, `\r` ignored).  
Host is the Raspberry Pi. Device is the Arduino Mega 2560.

This file is the contract. Firmware and the host simulator implement the same grammar.

## Handshake

```
> HELLO KRRL/1
< HELLO MEGA KRRL/1
```

If the Mega is silent, the host retries HELLO every 500 ms.

## Host → Mega

| Command | Meaning |
|---|---|
| `HELLO KRRL/1` | Protocol hello |
| `PING` | Immediate `PONG` |
| `SET RPM <f>` | Platter target RPM (`0`, `33.333`, `45`, `78`) |
| `SET XVEL <f>` | X lead-screw velocity, mm/s (signed: + toward spindle) |
| `SET X <f>` | X target radius, mm |
| `SET Z <f>` | Z target depth, mm (0 = retracted) |
| `HEAT <f>` | Stylus target °C (`0` = off) |
| `VAC 0` / `VAC 1` | Chip vacuum |
| `HOME X` / `HOME Z` / `HOME ALL` | Home to outer / up limits |
| `JOG X <f>` | Relative X move, mm |
| `JOG Z <f>` | Relative Z move, mm |
| `START` | Arm cut feed (interlocks required) |
| `ABORT` | Firmware abort sequence |
| `ZERO X` | Set current X as reported position (after home) |

Unknown commands: `ERR UNKNOWN`.

## Mega → Host

Telemetry at 10–20 Hz:

```
TEL rpm=33.331 x=142.20 z=0.040 t=179.8 vac=1 estop=0 state=CUT xhomed=1 zhomed=1
```

| Field | Unit |
|---|---|
| `rpm` | measured platter RPM |
| `x` | mm radius |
| `z` | mm depth |
| `t` | stylus °C |
| `vac` | 0/1 |
| `estop` | 1 = pressed |
| `state` | `IDLE` `HOMING` `READY` `SPINUP` `CUT` `ABORT` `FAULT` |
| `xhomed` `zhomed` | 0/1 |

Events:

```
EVT HOMED X
EVT HOMED Z
EVT AT_SPEED
EVT ABORTED
EVT DONE
```

Errors:

```
ERR ESTOP
ERR HEATER_OPEN
ERR NOT_HOMED
ERR NOT_AT_SPEED
ERR HEAT_BAND
ERR VAC_REQUIRED
ERR LIMIT
ERR UNKNOWN
```

`START` replies `OK` or `ERR …`. Other valid commands reply `OK` after they are accepted (homing completes later via `EVT`).

## Interlocks for START

All must hold:

1. `estop=0`
2. `xhomed=1` and `zhomed=1`
3. Platter RPM within ±0.3 of target (if target > 0)
4. Heater within ±5 °C of target (if target > 0)
5. Vacuum on if the host required it for this cut (host checks; Mega only checks `VAC` if `HEAT` > 0)

## Abort sequence (firmware)

Runs on `ABORT`, E-stop, or host-watchdog timeout (2 s with heater on):

1. Z retract to `z_retract_mm`
2. X velocity 0
3. Platter RPM ramp to 0
4. Heater off
5. Vacuum left as-is (host turns it off after chips settle)

## TMC2209

STEP/DIR at runtime. UART on `Serial1` (Mega pins 18/19) for current and microsteps at boot. Addresses via MS1/MS2: 0 platter, 1 X, 2 Z.

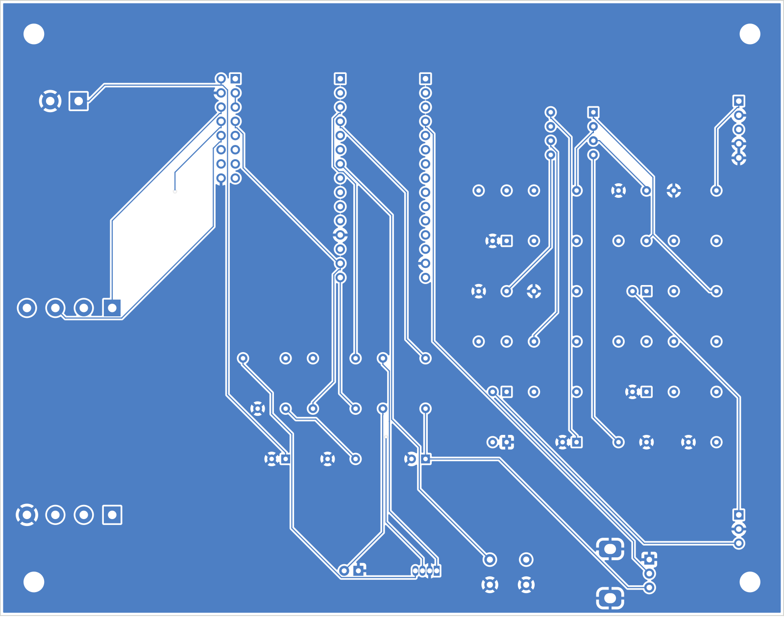
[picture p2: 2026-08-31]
hardware/player_pcb/render_bottom.png

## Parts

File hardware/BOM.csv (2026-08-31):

Subsystem | Item | Qty | Spec | Example part | Applies to | Notes
Drive | Platter spindle bearing | 2 | Angular-contact ball, bore 25-30 mm, P5/ABEC-5 | 7206-P5 (pair) | both | Back-to-back (DB/O); light-medium preload for rim/moment stiffness
Drive | Platter spindle bearing (alt) | 1 | Crossed-roller / four-point thin-section, bore to boss | THK RA / IKO CRB | both | Alternative: highest tilt stiffness per height; needs flat housing
Drive | Platter spindle | 1 | Ground hardened steel, Ø25-30 mm, seats h6 | custom | both | Housing bores H7; runout target <5 um TIR
Drive | Sub-platter / drive pulley | 1 | Aluminium, crowned belt surface, on spindle | custom | both | Driven pulley; sized for ~1:1 ratio
Drive | Platter | 1 | Aluminium, 356 mm (14 in) OD, ribbed/balanced | custom | both | Stiff and balanced; optional index track (see docs/TACHOMETER.md)
Drive | Motor pulley | 1 | Aluminium, crowned, dia for ~1:1 (<=2:1) ratio | custom | both | Ratio limited by 20 kHz step ISR (keep <8 kHz steps/s)
Drive | Drive belt | 1 | Flat 6 mm x 0.5-0.65 mm PU/neoprene, endless (or round O3-4 mm) | Gates/Habasit flat | both | Isolation belt; GT2/6 mm timing belt only if positive drive needed
Drive | Idler pulley (tensioner) | 1 | Ball-bearing, crowned | bearing idler | both | Low drag; crown self-tracks the belt
Drive | Tensioner arm | 1 | Anodised/polished aluminium pivot arm | custom | both | Increases wrap to >=180 deg; aesthetic
Drive | Tensioner preload | 1 | Concealed extension spring or neodymium magnet pair | spring/N42 magnets | both | Constant-tension; set belt tension 2-5 N
Motor | Stepper motor | 1 | NEMA 17 high-torque, >=0.5 N.m, ~1.5 A/ph, 1.8 deg | 17HS19-2004S1 | both | Shared baseline; rate-slewed; open-loop torque margin
Motor | Stepper motor (heavy-cut alt) | 1 | NEMA 23, 1.2-1.9 N.m | 57-frame | lathe | Use if cutting loads high; needs bigger driver
Motor | Stepper driver | 1 | TMC2209 STEP/DIR + UART, ~1.7 A RMS | TMC2209 module | player | Player = 1 (platter). stealthChop for quiet
Motor | Stepper driver | 3 | TMC2209 STEP/DIR + UART | TMC2209 module | lathe | Lathe = platter + X + Z
Motor | Stepper driver (big-motor alt) | 1 | TMC5160 or DM542-class | TMC5160 / DM542 | lathe | Only with NEMA 23 beyond TMC2209 current
Motor | Motor supply | 1 | 24 V regulated | 24 V PSU | both | Keep isolated from phono supply
Sensor | Optical index sensor | 1 | 5 V digital, slotted or reflective, 1 pulse/rev | slot opto / TCRT5000 | lathe | OPTIONAL lathe-only passive at-speed monitor (docs/TACHOMETER.md); player has no sensor
Control | Microcontroller | 1 | Arduino Nano (ATmega328P), crystal-clocked | Nano | player | Crystal (not resonator) for open-loop speed stability
Control | Microcontroller | 1 | Arduino Mega 2560 | Mega 2560 | lathe
Control | Speed/transport buttons | 5 | Momentary, NO, to GND | tact/panel switch | player | 33 / 45 / 78 / START / STOP
Control | Pitch fader | 1 | 10 k linear potentiometer | 10k lin pot | player | Centre detent = 0%, ends = +/-8%
Control | Status LED | 1 | onboard / panel | - | player | off=stopped / blink=spinning up / solid=at speed
Phono | Dual op-amp | 1 | Low-noise, unity-gain stable | NE5532 / OPA2134 / LM4562 | player | One package = stereo; active-feedback RIAA
Phono | Cartridge load resistor | 2 | 47 kohm 1% metal film | - | player | At preamp input
Phono | Cartridge load cap | 2 | ~100 pF (total incl. cable 150-300 pF) | C0G/NP0 | player | Match cartridge spec
Phono | RIAA feedback resistors | 4 | ~100 kohm and ~7.5 kohm, 1% metal film | - | player | R_A/R_B per channel; verify with RIAA calculator
Phono | RIAA feedback caps | 4 | ~33 nF and ~10 nF, film 1-2.5% | polypropylene/polystyrene | player | C_A/C_B per channel; C_B*R_B = 75 us
Phono | Gain/DC-block parts | per ch | Rg ~1 kohm; Cg ~100 uF; Cin ~1-3.3 uF; Rout ~100 ohm; Cout ~2.2-10 uF | - | player | Sets midband gain ~40 dB and AC coupling
Phono | Phono supply | 1 | Linear regulated +/-12..15 V (or 24 V + virtual ground) | linear reg | player | SEPARATE from motor 24 V rail
Phono | Shielded enclosure | 1 | Steel / mu-metal box | - | player | Critical: 5 mV signal near stepper
Phono | Line output | 1 | RCA / 3.5 mm, AC-coupled ~100 ohm out | - | player | ~0.3-1 V RMS to a line input

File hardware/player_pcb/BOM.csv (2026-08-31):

Qty | Value | Footprint | References
3 | 100u | CP_Radial_D6.3mm_P2.50mm | C_GL;C_GR;C_VMOT
3 | 10u | CP_Radial_D6.3mm_P2.50mm | C_5VB;C_VNB;C_VPB
2 | 3u3 | CP_Radial_D6.3mm_P2.50mm | C_OL;C_OR
4 | 100n | C_Disc_D5.0mm_W2.5mm_P5.00mm | C_5V;C_VIO;C_VN;C_VP
2 | 100p | C_Disc_D5.0mm_W2.5mm_P5.00mm | C_LDL;C_LDR
2 | 10n | C_Disc_D5.0mm_W2.5mm_P5.00mm | C_BL;C_BR
2 | 33n | C_Disc_D5.0mm_W2.5mm_P5.00mm | C_AL;C_AR
1 | NE5532 | DIP-8_W7.62mm | U2
1 | POWER | LED_D5.0mm | D_PWR
1 | RGB_MODE | LED_D5.0mm-4_RGB | D_RGB
4 | M3 | MountingHole_3.2mm_M3 | H1;H2;H3;H4
1 | LINE_OUT | PinHeader_1x03_P2.54mm_Vertical | J_OUT
1 | CART_IN | PinHeader_1x05_P2.54mm_Vertical | J_CART
1 | Nano_A | PinHeader_1x15_P2.54mm_Vertical | J1
1 | Nano_B | PinHeader_1x15_P2.54mm_Vertical | J2
1 | TMC2209 | PinHeader_2x08_P2.54mm_Vertical | M1
1 | 10k_SPEED | Potentiometer_Alps_RK09K_Single_Vertical | RV1
2 | 100R | R_Axial_DIN0207_L6.3mm_D2.5mm_P7.62mm_Horizontal | R_OL;R_OR
2 | 100k | R_Axial_DIN0207_L6.3mm_D2.5mm_P7.62mm_Horizontal | R_AL;R_AR
4 | 1k | R_Axial_DIN0207_L6.3mm_D2.5mm_P7.62mm_Horizontal | R_GL;R_GR;R_PWR;R_UART
2 | 220R | R_Axial_DIN0207_L6.3mm_D2.5mm_P7.62mm_Horizontal | R_B;R_G
1 | 330R | R_Axial_DIN0207_L6.3mm_D2.5mm_P7.62mm_Horizontal | R_R
2 | 47k | R_Axial_DIN0207_L6.3mm_D2.5mm_P7.62mm_Horizontal | R_LDL;R_LDR
2 | 7k5 | R_Axial_DIN0207_L6.3mm_D2.5mm_P7.62mm_Horizontal | R_BL;R_BR
1 | MODE | SW_PUSH_6mm | SW1
1 | PWR_24V | TerminalBlock_bornier-2_P5.08mm | J_PM
1 | MOTOR | TerminalBlock_bornier-4_P5.08mm | J_MOT
1 | PWR_5V_12V | TerminalBlock_bornier-4_P5.08mm | J_PL

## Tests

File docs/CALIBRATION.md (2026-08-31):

# Platter speed calibration

Both KRRL-01 machines run the platter **open-loop**: a stepper turns the belt at
a rate set purely by the step timing, and torque margin (not feedback) keeps it
on speed. There is no runtime speed control loop. That makes speed accuracy a
one-time **calibration** job, plus a check that the mechanicals are good enough.

This applies to both the lathe (Mega) and the player (Nano) — they share the
platter and drive.

## What sets the speed (and what can be wrong)

Platter speed = `step_rate x (1 / steps_per_rev)`, and the step rate comes
straight from the timer (`OCR1A = F_CPU / 8 / ISR_HZ`). So total speed error is
the product of two constant scale factors, plus one thing calibration cannot
fix:

1. **Controller timebase — the dominant error.** Many Nano/Mega clones clock
   from a **ceramic resonator (±0.5%, and it drifts with temperature)**. That is
   ~0.17 rpm at 33⅓ on its own. A real **crystal is ±20–50 ppm**; a **TCXO is
   ±2 ppm**. Open-loop high tolerance *requires* a stable, accurate step clock:
   use a genuine crystal-clocked board, or drive the step source from a TCXO.
2. **Mechanical scale** — `steps_per_rev` = microsteps × motor steps/rev ×
   pulley ratio. A constant factor you null during calibration.
3. **Wow & flutter** — intra-revolution variation (belt, bearing, pulley
   eccentricity, microstep non-uniformity). Open-loop cannot remove it, so
   calibration must **measure** it to confirm the build is good enough.

> **Cardinal rule:** the calibration reference must be *independent of the
> board's clock* and about **10× better** than your target tolerance. You cannot
> calibrate the board's timebase with the board's own timebase.

## Sensor setups, best first

### 1. High-count optical encoder + disciplined timebase (recommended bench rig)

The most versatile: it yields both average speed (to ppm) and a wow/flutter
spectrum from one instrument.

- **Sensor:** a transmissive glass/etched encoder disc or a commercial rotary
  encoder, **≥2000 CPR**, coupled to the spindle. Mind coupling runout — it
  shows up as flutter. (Note the inversion from runtime: for *offline*
  calibration you want as many lines as possible; CPU cost is irrelevant.)
- **Timebase:** capture the A channel on a counter/DAQ referenced to a **TCXO or
  GPS-disciplined 10 MHz** (a lab reciprocal frequency counter with an external
  reference is ideal).
- **Compute:** counts over a long gate (e.g. 100 s) → average speed to ppm;
  edge-to-edge intervals → instantaneous velocity → wow/flutter.

### 2. 3150 Hz test record + wow/flutter analysis (gold standard for the player)

Per **DIN 45507 / IEC 60386**: play a standard 3150 Hz reference LP and measure
the recovered tone with a **W&F meter** or PC audio analysis. This measures
true, *as-heard* speed and W&F through the whole chain including the record. It
is the definitive turntable calibration — but it needs a cartridge/tonearm +
phono preamp + audio interface, i.e. a pickup the motion-only player does not
have by default. Use it if a pickup is fitted (or added for QA).

### 3. Handheld laser photo-tachometer + reflective tape (quick check)

~$20, reads **average RPM to ~±0.05%**, no W&F, and its own timebase is only
moderate. Good for a go/no-go, not for ppm work.

### 4. Calibrated LED strobe disc (quick check)

An LED strobe driven from an **accurate** source (not mains) reads ~0.1% by eye
and makes flutter visible as edge "shimmer". Cheap sanity check.

## Procedure

1. **Fix the timebase.** Confirm the board is crystal/TCXO-clocked (not a
   resonator). Log the actual clock frequency against your reference; a stable
   offset is fine because it folds into step 3.
2. **Measure true speed.** Command 33⅓, 45 and 78 and measure actual platter
   speed with an independent, well-clocked reference (setup 1 or 2). One speed is
   enough if the drive is a fixed ratio; measuring all three confirms it.
3. **Null the error.** The error is a scale factor `k = commanded / measured`.
   Apply it either way:
   - adjust `steps_per_rev` → `steps_per_rev x k`, or
   - set the fine ppm trim: `PLATTER_CAL_PPM` (lathe, `firmware/krrl_mega/config.h`)
     or `KRRL_SPEED_TRIM_PPM` (player, `firmware/krrl_player/playspeed.h`), where
     `ppm = (k - 1) x 1e6`.
   Reflash and re-measure to confirm.
4. **Check wow & flutter.** Capture the spectrum (setup 1 or 2). Good decks are
   roughly **< 0.1% WRMS**. If one line dominates (e.g. once-per-rev), fix it
   mechanically — open-loop won't.
5. **Verify over temperature.** Re-check cold and warm; resonators in particular
   move here. If it drifts, improve the timebase (step 1).

## Where the knobs live

| Machine | steps/rev | fine ppm trim |
|---|---|---|
| Lathe (Mega) | `PLATTER_STEPS_PER_REV` in `firmware/krrl_mega/config.h` (and `platter.steps_per_rev` in `config/machine.yaml`) | `PLATTER_CAL_PPM` |
| Player (Nano) | `KRRL_PLATTER_STEPS_PER_REV` in `firmware/krrl_player/playspeed.h` | `KRRL_SPEED_TRIM_PPM` |

The lathe's optional once-per-rev optical index (see
[TACHOMETER.md](TACHOMETER.md)) is a passive at-speed monitor; because it samples
only once per revolution it is not a calibration reference. The player has no
speed sensor at all. Either way, calibrate with the independent, high-resolution
setups above.

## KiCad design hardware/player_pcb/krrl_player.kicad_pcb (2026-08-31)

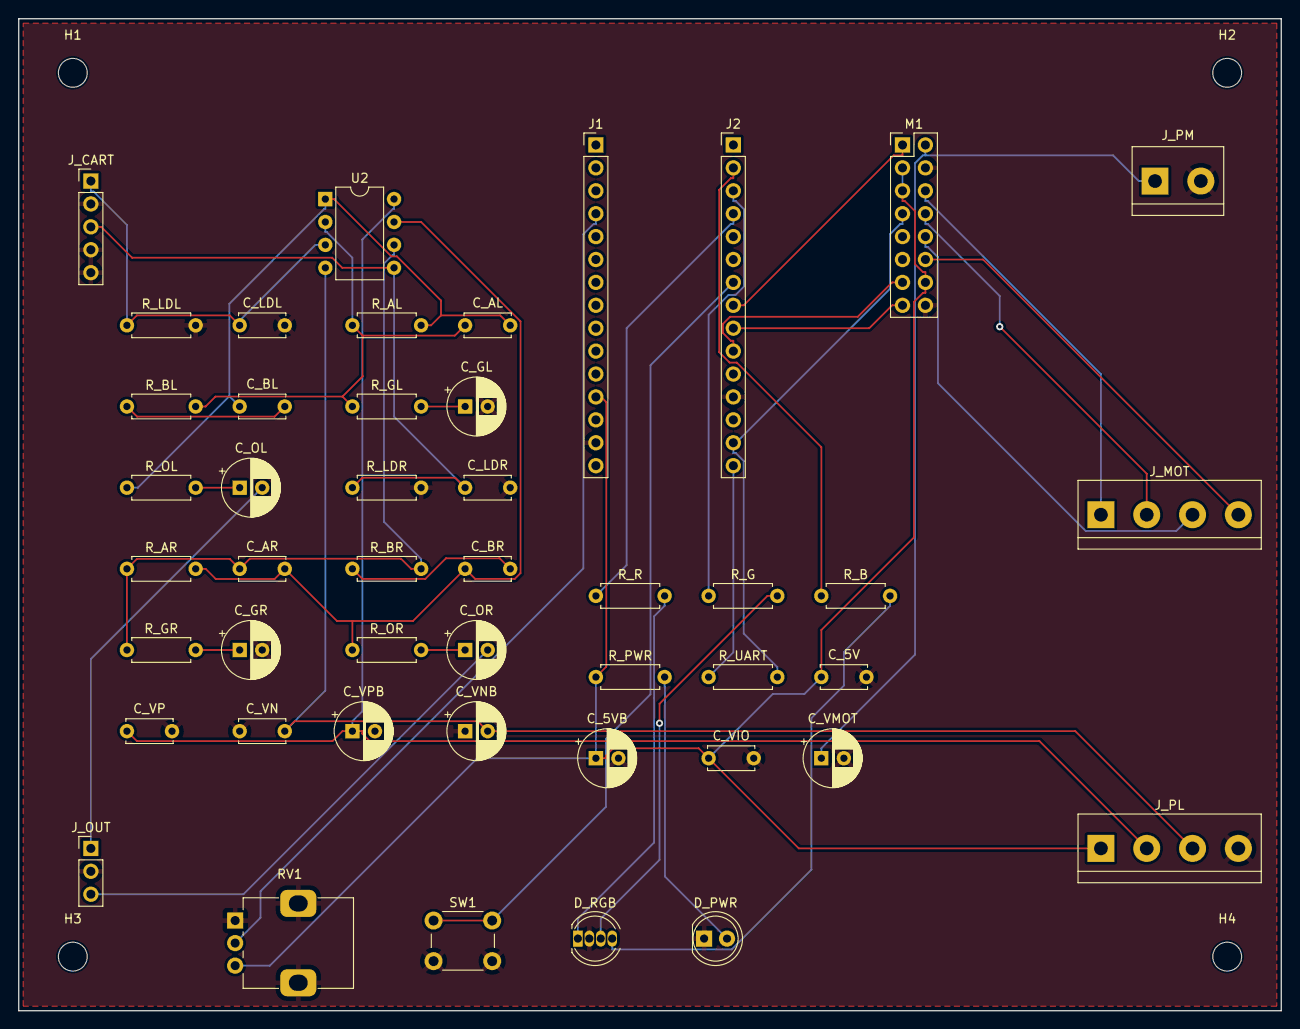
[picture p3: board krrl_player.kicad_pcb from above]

Board: 2 copper layers, 140.0 x 110.0 mm, 50 parts (0 on the bottom side), 37 nets.

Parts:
C_5V: 100n; C_Disc_D5.0mm_W2.5mm_P5.00mm
C_5VB: 10u; CP_Radial_D6.3mm_P2.50mm
C_AL: 33n; C_Disc_D5.0mm_W2.5mm_P5.00mm
C_AR: 33n; C_Disc_D5.0mm_W2.5mm_P5.00mm
C_BL: 10n; C_Disc_D5.0mm_W2.5mm_P5.00mm
C_BR: 10n; C_Disc_D5.0mm_W2.5mm_P5.00mm
C_GL: 100u; CP_Radial_D6.3mm_P2.50mm
C_GR: 100u; CP_Radial_D6.3mm_P2.50mm
C_LDL: 100p; C_Disc_D5.0mm_W2.5mm_P5.00mm
C_LDR: 100p; C_Disc_D5.0mm_W2.5mm_P5.00mm
C_OL: 3u3; CP_Radial_D6.3mm_P2.50mm
C_OR: 3u3; CP_Radial_D6.3mm_P2.50mm
C_VIO: 100n; C_Disc_D5.0mm_W2.5mm_P5.00mm
C_VMOT: 100u; CP_Radial_D6.3mm_P2.50mm
C_VN: 100n; C_Disc_D5.0mm_W2.5mm_P5.00mm
C_VNB: 10u; CP_Radial_D6.3mm_P2.50mm
C_VP: 100n; C_Disc_D5.0mm_W2.5mm_P5.00mm
C_VPB: 10u; CP_Radial_D6.3mm_P2.50mm
D_PWR: POWER; LED_D5.0mm
D_RGB: RGB_MODE; LED_D5.0mm-4_RGB
H1, H2, H3, H4: M3; MountingHole_3.2mm_M3
J1: Nano_A; PinHeader_1x15_P2.54mm_Vertical
J2: Nano_B; PinHeader_1x15_P2.54mm_Vertical
J_CART: CART_IN; PinHeader_1x05_P2.54mm_Vertical
J_MOT: MOTOR; TerminalBlock_bornier-4_P5.08mm
J_OUT: LINE_OUT; PinHeader_1x03_P2.54mm_Vertical
J_PL: PWR_5V_12V; TerminalBlock_bornier-4_P5.08mm
J_PM: PWR_24V; TerminalBlock_bornier-2_P5.08mm
M1: TMC2209; PinHeader_2x08_P2.54mm_Vertical
RV1: 10k_SPEED; Potentiometer_Alps_RK09K_Single_Vertical
R_AL: 100k; R_Axial_DIN0207_L6.3mm_D2.5mm_P7.62mm_Horizontal
R_AR: 100k; R_Axial_DIN0207_L6.3mm_D2.5mm_P7.62mm_Horizontal
R_B: 220R; R_Axial_DIN0207_L6.3mm_D2.5mm_P7.62mm_Horizontal
R_BL: 7k5; R_Axial_DIN0207_L6.3mm_D2.5mm_P7.62mm_Horizontal
R_BR: 7k5; R_Axial_DIN0207_L6.3mm_D2.5mm_P7.62mm_Horizontal
R_G: 220R; R_Axial_DIN0207_L6.3mm_D2.5mm_P7.62mm_Horizontal
R_GL: 1k; R_Axial_DIN0207_L6.3mm_D2.5mm_P7.62mm_Horizontal
R_GR: 1k; R_Axial_DIN0207_L6.3mm_D2.5mm_P7.62mm_Horizontal
R_LDL: 47k; R_Axial_DIN0207_L6.3mm_D2.5mm_P7.62mm_Horizontal
R_LDR: 47k; R_Axial_DIN0207_L6.3mm_D2.5mm_P7.62mm_Horizontal
R_OL: 100R; R_Axial_DIN0207_L6.3mm_D2.5mm_P7.62mm_Horizontal
R_OR: 100R; R_Axial_DIN0207_L6.3mm_D2.5mm_P7.62mm_Horizontal
R_PWR: 1k; R_Axial_DIN0207_L6.3mm_D2.5mm_P7.62mm_Horizontal
R_R: 330R; R_Axial_DIN0207_L6.3mm_D2.5mm_P7.62mm_Horizontal
R_UART: 1k; R_Axial_DIN0207_L6.3mm_D2.5mm_P7.62mm_Horizontal
SW1: MODE; SW_PUSH_6mm
U2: NE5532; DIP-8_W7.62mm

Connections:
+5V: C_5V.1, C_5VB.1, C_VIO.1, J1.12, J_PL.1, M1.3, M1.5, M1.14, RV1.3, R_PWR.1
+12V: C_VP.1, C_VPB.1, J_PL.2, U2.8
+24V: C_VMOT.1, J_PM.1, M1.2
-12V: C_VN.2, C_VNB.2, J_PL.3, U2.4
BML: C_BL.2, R_BL.1
BMR: C_BR.2, R_BR.1
DIR: J2.9, M1.15
EN: J2.8, M1.1
FBL: C_AL.1, R_AL.1, R_BL.2, R_GL.1, U2.2
FBR: C_AR.1, R_AR.1, R_BR.2, R_GR.1, U2.6
GML: C_GL.1, R_GL.2
GMR: C_GR.1, R_GR.2
GND: C_5V.2, C_5VB.2, C_GL.2, C_GR.2, C_LDL.2, C_LDR.2, C_VIO.2, C_VMOT.2, C_VN.1, C_VNB.1, C_VP.2, C_VPB.2, D_PWR.1, D_RGB.2, J1.14, J2.12, J_CART.2, J_CART.4, J_CART.5, J_OUT.2, J_PL.4, J_PM.2, M1.4, M1.16, RV1.1, RV1.MP, R_LDL.2, R_LDR.2, SW1.2
INL: C_LDL.1, J_CART.1, R_LDL.1, U2.3
INR: C_LDR.1, J_CART.3, R_LDR.1, U2.5
LEDB: J2.2, R_B.1
LEDG: J2.3, R_G.1
LEDR: J2.4, R_R.1
LOUTL: C_OL.2, J_OUT.1
LOUTR: C_OR.2, J_OUT.3
M1A: J_MOT.3, M1.10
M1B: J_MOT.4, M1.12
M2A: J_MOT.2, M1.8
M2B: J_MOT.1, M1.6
MODE: J2.7, SW1.1
OLL: C_OL.1, R_OL.2
OLR: C_OR.1, R_OR.2
OUTL: C_AL.2, C_BL.1, R_AL.2, R_OL.1, U2.1
OUTR: C_AR.2, C_BR.1, R_AR.2, R_OR.1, U2.7
PDN: J2.14, M1.7, R_UART.2
POTW: J1.4, RV1.2
PWRA: D_PWR.2, R_PWR.2
RGB_B: D_RGB.4, R_B.2
RGB_G: D_RGB.3, R_G.2
RGB_R: D_RGB.1, R_R.2
STEP: J2.10, M1.13
TX: J2.15, R_UART.1

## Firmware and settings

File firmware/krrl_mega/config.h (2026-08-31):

#pragma once

#include <Arduino.h>

#define KRRL_PROTO "KRRL/1"

#define PIN_PLATTER_STEP 22
#define PIN_PLATTER_DIR  23
#define PIN_PLATTER_EN   24
#define PIN_X_STEP       25
#define PIN_X_DIR        26
#define PIN_X_EN         27
#define PIN_Z_STEP       28
#define PIN_Z_DIR        29
#define PIN_Z_EN         30
#define PIN_VACUUM       31
#define PIN_X_MIN        32
#define PIN_X_MAX        33
#define PIN_Z_MIN        34
#define PIN_Z_MAX        35
#define PIN_HEATER       6
#define PIN_THERM        A0
#define PIN_ESTOP        2
#define PIN_TACH         3

#define AXIS_P 0
#define AXIS_X 1
#define AXIS_Z 2

#define ISR_HZ 20000UL
#define TEL_MS 50
#define HOST_WATCHDOG_MS 2000

#define X_STEPS_PER_MM 400.0f
#define Z_STEPS_PER_MM 2000.0f
#define PLATTER_STEPS_PER_REV 3200.0f
#define X_MIN_MM 52.0f
#define X_MAX_MM 160.0f
#define Z_RETRACT_MM 2.0f
#define Z_MAX_MM 4.0f

#define HEATER_MAX_C 220.0f
#define HEATER_KP 12.0f
#define HEATER_KI 0.4f
#define HEATER_KD 8.0f

#define RPM_BAND 0.3f
#define HEAT_BAND_C 5.0f

/* Fine open-loop speed calibration (ppm). Set after measuring the true platter
 * speed against a calibrated reference; see docs/CALIBRATION.md. 0 = none. */
#define PLATTER_CAL_PPM 0

enum State : uint8_t {
  ST_IDLE = 0,
  ST_HOMING,
  ST_READY,
  ST_SPINUP,
  ST_CUT,
  ST_ABORT,
  ST_FAULT
};

const char *state_name(State s);

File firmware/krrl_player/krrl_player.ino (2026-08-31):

#include "config.h"
#include "playspeed.h"
#include "platter.h"
#include "controls.h"
#include "tmc.h"

/* KRRL-01 Player: hardware-only belt-drive turntable on an Arduino Nano.
 *
 * Panel: ( MODE momentary )  ( SPEED pot )  [RGB mode LED]  [power LED]
 *  - MODE cycles STOP -> 33 -> 45 -> 78 -> STOP. STOP spins the platter down.
 *  - SPEED pot is a continuous pitch trim: centre detent = 0%, ends = +/-8%.
 *  - RGB LED shows the mode: off = stopped, green = 33, blue = 45, red = 78;
 *    it blinks while spinning up and goes solid at speed.
 *  - Power LED is hardwired to +5V on the board.
 *  - Speed is open-loop feedforward; calibrate per docs/CALIBRATION.md. */

enum Mode { MODE_STOP = 0, MODE_33, MODE_45, MODE_78, MODE_COUNT };

static uint8_t mode = MODE_STOP;
static float pitch_pct = 0.0f;

static float mode_rpm(uint8_t m) {
  switch (m) {
    case MODE_33: return KRRL_RPM_33;
    case MODE_45: return KRRL_RPM_45;
    case MODE_78: return KRRL_RPM_78;
    default:      return 0.0f;   /* STOP */
  }
}

static void apply_speed() {
  platter_set_target_rpm(krrl_pitched_rpm(mode_rpm(mode), pitch_pct));
}

/* Common-cathode RGB: HIGH = on. Off when stopped; the mode colour blinks
 * while spinning up and is solid once at speed. */
static void update_led() {
  bool r = mode == MODE_78;
  bool g = mode == MODE_33;
  bool b = mode == MODE_45;
  bool on = mode != MODE_STOP &&
            (platter_at_speed() || ((millis() / 250) & 1));
  digitalWrite(PIN_LED_R, (r && on) ? HIGH : LOW);
  digitalWrite(PIN_LED_G, (g && on) ? HIGH : LOW);
  digitalWrite(PIN_LED_B, (b && on) ? HIGH : LOW);
}

void setup() {
  tmc_begin();          /* optional TMC2209 UART config (D0/D1) */
  platter_begin();
  controls_begin();
  pinMode(PIN_LED_R, OUTPUT);
  pinMode(PIN_LED_G, OUTPUT);
  pinMode(PIN_LED_B, OUTPUT);
  update_led();
  apply_speed();
}

void loop() {
  controls_poll();

  if (press_mode()) mode = (mode + 1) % MODE_COUNT;
  pitch_pct = controls_pitch_pct();

  apply_speed();
  platter_poll();
  update_led();
}

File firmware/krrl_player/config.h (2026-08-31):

#pragma once

#include <Arduino.h>
#include "playspeed.h"

/* KRRL-01 Player: minimal belt-drive turntable on an Arduino Nano.
 *
 * Playback only: 33/45/78 with a +/-8% pitch trim, start/stop. No host, no
 * serial protocol, no cutter/heater/vacuum. It shares the lathe's belt drive
 * motor, TMC2209 driver and the open-loop step-rate motion core. */

/* ---- Platter driver (single TMC2209, STEP/DIR) ---- */
#define PIN_PLATTER_STEP 3
#define PIN_PLATTER_DIR  4
#define PIN_PLATTER_EN   5   /* active LOW enable */

/* ---- Front panel ---- */
#define PIN_BTN_MODE     6   /* momentary to GND, INPUT_PULLUP; cycles STOP/33/45/78 */
#define PIN_PITCH_POT    A0  /* speed pot wiper; ends to 5V/GND (pitch trim) */

/* Multicolour mode LED (common-cathode RGB, each anode via a series R). */
#define PIN_LED_R        9
#define PIN_LED_G        10
#define PIN_LED_B        11
/* The power LED is hardwired to +5V on the board and is not driven here. */

/* ---- Step generation ---- */
#define ISR_HZ 20000UL       /* Timer1 step tick, matches the lathe core */

/* ---- Control tunables ---- */
#define DEBOUNCE_MS      25
#define POT_MAX_COUNTS   1023  /* 10-bit ADC full scale */
#define POT_DEADBAND     10    /* +/- counts around centre that read as 0% */
#define POT_EMA_ALPHA    0.20f /* fader smoothing (0..1); higher = snappier */

/* Platter acceleration as a step-rate slew, so the belt starts and changes
 * speed smoothly instead of stalling. sps added/removed per control poll. */
#define SLEW_SPS_PER_MS  6.0f

/* Default speed selected at power-on. */
#define DEFAULT_RPM KRRL_RPM_33

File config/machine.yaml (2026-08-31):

# KRRL-01 machine calibration. Host reads this; firmware pins are in config.h.
name: KRRL-01
serial:
  port: /dev/ttyACM0
  baud: 115200
audio:
  device: default
  rate: 48000
  quantum: 1024
camera:
  device: /dev/video0
  width: 1280
  height: 720
# platter runs open-loop; calibrate steps_per_rev per docs/CALIBRATION.md.
# tach_ppr/rpm_band drive the passive optical at-speed monitor only.
platter:
  steps_per_rev: 3200
  tach_ppr: 1
  rpm_band: 0.3
x:
  steps_per_mm: 400.0
  min_mm: 52.0
  max_mm: 160.0
  home_dir: outer
z:
  steps_per_mm: 2000.0
  retract_mm: 2.0
  min_mm: 0.0
  max_mm: 4.0
heater:
  kp: 12.0
  ki: 0.4
  kd: 8.0
  max_c: 220.0
  band_c: 5.0
cut:
  require_vacuum: true
  lock_groove_revs: 3
host:
  bind: 0.0.0.0
  port: 8080
  tel_hz: 15

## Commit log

2026-08-15 Add lath control software stack
    [machine.yaml]
2026-08-17 Add Nano player turntable firmware variant
    Minimal playback-only turntable on an Arduino Nano: 33/45/78 speeds, +/-8%
    pitch trim with up/down (hold to sweep), start/stop. No host, UI or serial
    protocol. Reuses the lathe belt drive, TMC2209 driver and the open-loop
    step-rate motion core (shared speed math in playspeed.h, single-axis platter
    motion derived from krrl_mega/motion.cpp).
    Includes native host tests for the speed/pitch math and a start/speed/pitch/
    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
2026-08-17 Player: use a continuous analog pitch fader instead of up/down buttons
    Pitch is now a 10k linear potentiometer on A0 (centre detent = 0%, ends =
    +/-8%) with a centre deadband and EMA smoothing. Adds a pure, testable ADC->
    pitch mapping (krrl_pot_to_pitch_pct) to the shared header; drops the PITCH+/-
    buttons and their repeat logic. Docs, wiring and native tests updated.
2026-08-17 Add closed-loop optical tachometer to player + platter marking/machining docs
    Player firmware now closes the platter speed loop on a 1-pulse-per-rev optical
    tach (pin D2/INT0), mirroring the lathe: feedforward step rate plus a clamped
    proportional trim from the measured RPM, with an open-loop fallback when no
    sensor is fitted. LED now shows speed lock (off/blink/solid). Adds shared,
    tested tach helpers (krrl_tach_rpm, krrl_tach_trim_sps) to playspeed.h.
    Adds docs/TACHOMETER.md explaining how the closed loop works and how to mark
    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
2026-08-27 Commit platter drive to open-loop feedforward; add calibration guide
    Drop the runtime speed control loop on both machines and rely on the stepper
    feedforward plus torque margin, as decided after concluding a 1-mark/rev tach
    is too slow (0.5-1.3 Hz) and blind to wow/flutter for a control loop.
    - Player: platter runs feedforward + slew only; the optical index (D2) is now
    an optional PASSIVE at-speed monitor for the LED, never steering the rate.
    - Lathe: remove the proportional tach trim from motion.cpp; the tach stays a
    passive monitor for telemetry rpm and the START at-speed interlock.
    - Add a fine ppm calibration trim to both (KRRL_SPEED_TRIM_PPM / PLATTER_CAL_PPM);
    steps_per_rev rema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
    [machine.yaml]
2026-08-27 Add hardware notes and BOM for shared belt-drive and player phono
    New hardware/ folder documenting the shared raised-platter belt drive (belt and
    tensioner around the central spindle, X axis passing underneath):
    - drive.md: platter spindle bearings for moment/tilt rigidity at the 14" rim
    (preloaded back-to-back angular-contact pair, or crossed-roller alt); flat/
    round isolation belt spec and ~1:1 ratio bounded by the 20 kHz step ISR;
    NEMA 17/23 stepper sizing and TMC2209/TMC5160 drive; and an aesthetic
    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
    [BOM.csv]
2026-08-27 Complete player optical-tach removal (fully open-loop, sensor-less)
    Finish removing the optical tach from the player: drop PIN_TACH, the tach ISR,
    measured_rpm/platter_locked and RPM_BAND; the at-speed LED now reflects the
    feedforward ramp via platter_at_speed(). This also fixes the player build, which
    was broken in 0676bde (playspeed.h dropped krrl_tach_rpm while platter.cpp and
    the test still called it).
    Reconcile docs to match: the player is sensor-less; the optical index + its
    marking/machining are a lathe-only option. Updated TACHOMETER.md, PLAYER.md,
    CALIBRATION.md, hardware/README.md and BOM.csv (sensor is lathe-only). The lathe
    keeps its passive tach monitor unchanged.
    Co-authored-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
    [BOM.csv]
2026-08-31 Player firmware: single mode button + RGB mode LED front panel
    Replace the five speed/transport buttons with one momentary MODE button that
    cycles STOP -> 33 -> 45 -> 78 (STOP spins down), and a common-cathode RGB mode
    LED (off/green/blue/red; blinks while spinning up, solid at speed). Speed pot
    (pitch trim) unchanged on A0. Pins matched to the new single-board design
    (hardware/player_pcb): STEP/DIR/EN D3-5, MODE D6, RGB D9-11, pot A0. Power LED
    is hardwired to +5V. Docs updated.
    [config.h, controls.cpp, krrl_player.ino]
2026-08-31 Add player single-board KiCad PCB (Nano + TMC2209 + RIAA + I/O)
    Fabricable 2-layer board integrating the Arduino Nano, a TMC2209 StepStick, the
    NE5532 RIAA phono preamp, and the front-panel I/O (mode momentary + RGB mode
    LED, speed pot, power LED). Powered from a separate external multi-rail PSU
    (+24V motor, +5V logic, +-12V analog) specified in the README; no on-board
    regulators. Open-loop drive, no speed sensor.
    The board is generated from source and fully autorouted:
    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
    [BOM.csv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]
